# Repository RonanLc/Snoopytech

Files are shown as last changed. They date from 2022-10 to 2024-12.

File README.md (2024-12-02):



# Snoopytech - Autonomous Robot Dog 🐕

## 🌟 Presentation

Snoopytech is an ambitious project for an autonomous quadruped robot, designed to explore complex environments by combining agility and embedded intelligence. The robot uses 3-degree-of-freedom legs, brushless motors and integrates a computational architecture based on Arduino and NVIDIA. Behave or he might bite ! 

## ⚙️ Key features

1. **Mechanical structure** : 

   - 3-axis legs with brushless motors for smooth, dynamic movement.
   - Robust, lightweight design for stability in a variety of environments.

2. **Electronic components** :

    - **Arduino**: Sensor management and basic motion coordination.
    - **NVIDIA Jetson**: Advanced processing for computer vision, data analysis and real-time decision-making.
    - [**Brushless ACK-5312CP motors**](https://fr.aliexpress.com/item/33027613653.html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): Brushless motor for dog joint with reversible ESCs
    - [**RP LIDAR**](https://www.amazon.fr/Scanradius-LIDAR-Sensorscanner-Vermeidung-Hindernissen-Navigation/dp/B07VLFGT27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): 360° LIDAR for environmental analysis
    - [**C505e HD Webcam**](https://www.amazon.fr/Logitech-Webcam-Micro-Longue-port%C3%A9e/dp/B08NZ52YYN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): HD camera for environmental analysis
    - [**MPU6050**](https://fr.aliexpress.com/item/32340949017.html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): IMU sensor with accelerometers and gyroscopes

3. **Software and algorithms** :

   - Motor control via specific controllers (ESC).
   - Implementation of kinematic models to ensure precise movement.
   - Integration of sensors for autonomous navigation.

## 🎯 Project objectives

- Develop a robot capable of walking, running and adapting to rough terrain.
- Incorporate artificial intelligence for tasks such as obstacle detection, object recognition and interaction with the environment.
- Test and validate locomotion and stability algorithms for quadruped robots.

## 🛠️ Project structure

The repository is organized as follows:

1. `Mechanical/` :
   - CAD design files and mechanical drawings.
   - Documentation on leg manufacturing and motor selection.

2. `Electronics/` :
   - Circuits for powering motors and interfacing with control boards.
   - ESC configuration for brushless motors.

3. `Software` :
   - Arduino code for low-level control of motors and sensors.
   - Python and C++ scripts for data processing and behavior management.
   - Simulation models to test algorithms before hardware integration.

4. `AI/` :
   - Computer vision models for real-time analysis (via Jetson).
   - Learning algorithms to optimize motion.

## 🚀 Progress and next steps

- **Current**: Tests of locomotion algorithms and motor calibration.
- **Upcoming** :
  - Full integration of sensors for autonomous navigation.
  - Development of a communication system for remote or collaborative control.
  - Energy optimization for extended autonomy.

## 📚 Documentation

- **Tutorials and Explanations**: Sample scripts are available in the `doc/` folder.

## 📫 Contact

If you have any questions or suggestions, please feel free to open an issue or contact me via [my GitHub](https://github.com/RonanLc).

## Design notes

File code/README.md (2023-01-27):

# Bilan programmation du 27/01/2023

## Introduction

Ce répertoire rassemble tous les programmes et parcelles de code qui ont été crées/utilisés dans le cadre de ce projet.
Il s'agit, pour la plupart, de code C++ car nous sommes encore au stade d'expérimentation. 
Nous implementerons des fonctions de traitements d'images et de classifications d'images à bord de la Jetson Nano lorsque nous aurons achevé d'écrire les librairies destinées à rendre notre robot fonctionnel.

## Librairies et classes utilisées/importées

Voici une liste de librairie que nous utilisons afin de rendre certains capteurs/actionneurs opérationnels :

1. [I2Cdev](https://github.com/jrowberg/i2cdevlib) 

Cette librairie facilite le contrôle de module communiquant avec l'Arduino par le biais de bus I2C. Nous l'utilisons notamment dans la librairie ```MPU6050```.

2. [MPU6050](https://github.com/jrowberg/i2cdevlib/tree/master/Arduino/MPU6050)

Cette librairie est destinée à controler le capteur GY-521 (gyroscope). Elle permet d'utiliser le DMP (digital motion processor) qui est sollicité pour renvoyer des données stables et lisibles. 
Nous implementons cette librairie dans la classe ```Gyroscope```.

3. [ServoTimer2-master](https://github.com/nabontra/ServoTimer2)

Cette librairie permet de controler les servomoteurs et ESC de notre robot en évitant de créer des conflits liés au Timer1 de l'Arduino. Nous l'implementons dans la classe ```CameraMount```.

## Librairies et classes apportées

Cette section regroupe les classes et les programmes que nous avons écrits. 

1. [Gyroscope](https://github.com/RonanLc/Snoopytech/tree/main/code/lib/Gyroscope)

Cette classe facilite l'utilisation du gyroscope GY-521. Elle implémente les classes MPU6050 et I2Cdev. 

Utilisation: 
- permet d'initialiser un gyroscope sur le pin 2 d'une Arduino Uno
- calcule et renvoie l'accelération réelle et le roulis/tangage/lacet du capteur

2. [CameraMount](https://github.com/RonanLc/Snoopytech/tree/main/code/lib/CameraMount) 

Cette classe crée des objets contrôlant une nacelle de notre robot. Une nacelle est une structure sur laquelle se monte des capteurs qui ont besoin d'une orientation indépendante du corps du robot. La nacelle se compose de deux servomoteurs SG-90.

Utilisation:
- permet d'initialiser les deux servomoteurs sur les pins passés en paramètre
- change le roulis et/ou le tangage de la nacelle selon un angle passé en paramètre
- réinitialise la position de la nacelle 
- renvoie la postion de la nacelle

## Programmes d'essais

1. [rpm_brushless](https://github.com/RonanLc/Snoopytech/tree/main/code/test/rpm_brushless.ino)

Ce programme permet de récuperer la vitesse de rotation d'un moteur brushless grâce à un capteur à effet Hall. Nous l'utilisons dans l'étude de l'asservissement de position des moteurs. 

2. [main.cpp](https://github.com/RonanLc/Snoopytech/blob/main/code/src/main.cpp) 

Ce programme est celui qui sera exécuté sur l'Arduino. Il regroupe toutes les classes utilisées. 
Pour l'instant, il permet de changer l'orientation des deux nacelles du robot selon l'inclinaison du gyroscope. 

## Jetson Nano

Nous nous sommes initiés aux possibles librairies et structures proposées par Nvidia visant à faire de l'IA (classification d'image, détection d'objets, estimation de profondeur, ...) sur la Jetson Nano à travers le cours dédié de [Nvidia](https://developer.nvidia.com/embedded/learn/jetson-ai-certification-programs#course_outline). 
En lançant le conteneur docker dédié, nous avons rencontré de nombreux problèmes de librairies manquantes ou obsolètes et avons décidé de poursuivre sur d'autres logiciels. 
Nous nous sommes notamment intéréssés aux programmes chargés dans le conteneur [Hello AI World](https://github.com/dusty-nv/jetson-inference) qui ciblent davantage les besoins de notre projet (détection d'objets et estimation de profondeur). Cependant, lorsque nous tentons de lancer des programmes permettant de visualier ce que la caméra enregistre, des erreurs de librairies manquantes apparaissent. Nous pensons qu'il s'agit des librairies CUDA, CUDNN ou TensorFLow qui sont obsolètes.

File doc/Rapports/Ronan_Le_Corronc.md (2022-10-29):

# **New -** Week 43 - October 28, 2022 - 22h

## Shoulder preliminary conception 

The leg was finish so I start working about the motor part and mostly **the shoulder part**. I made a lot of sketching because this part is the **most complex** of the leg build.

The shoulder must fit a lot of part in it :
- The 2 motors of the legs
- The belt of the hip speed reduction
- The 2 potentiometers to check the knee and hip position
- A cable connector to power all the leg part
- The pullet for the shoulder rotation

The difficulty here is to fit every thing in the shoulder. But the shoulder must be very **compact, light and also have a good design.**

## Shoulder modeling

I decided to made the shoulder in **2 part**, one for the top and one for the bottom. These parts will be made with a **3D printer**.

So I start to modeling the part to fix the shoulder on the frame. I decided to made an other tube, around the carbon fiber tube with 2 bearings.

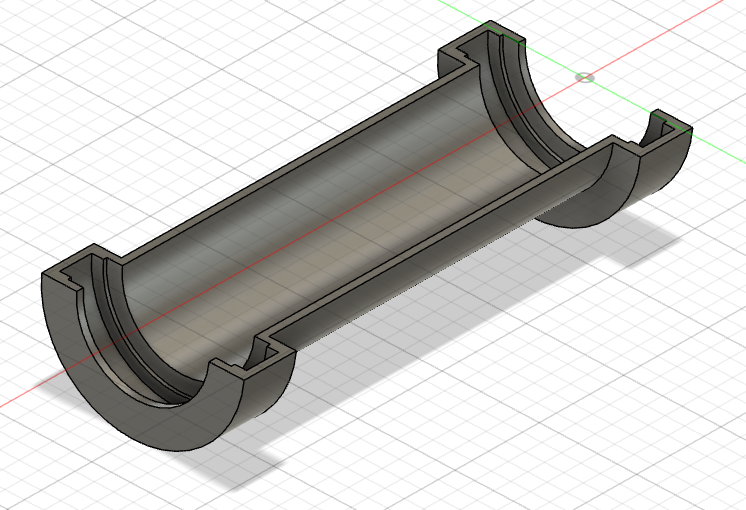
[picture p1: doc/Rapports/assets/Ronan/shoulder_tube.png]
Shoulder tube


After that I had to modeling someting to fix the 2 motors. I didn't want to fix the motors directly on 3D parts because it's not precise and solid enough.

So i decided to fix the motors on a **plexiglass piece**.

For that I modeled **a gutter** that can accommodate the plexiglass plate. So the 2 3D parts will close on the plexiglass piece.

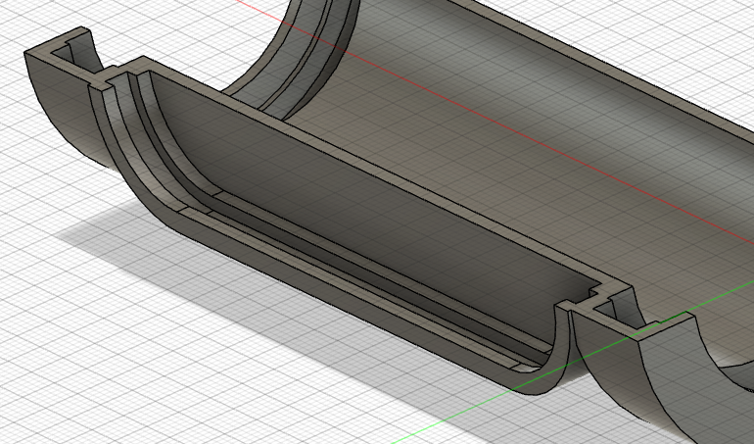
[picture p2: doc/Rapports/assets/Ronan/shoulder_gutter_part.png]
Shoulder gutter


The bottom part isn't finish yet but I start a assembly of the shoulder. I had the bottom and the top part, and the 2 bearing.

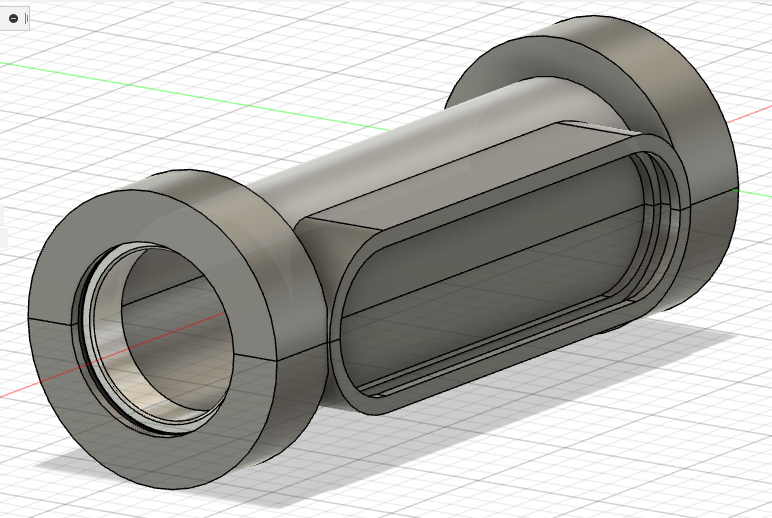
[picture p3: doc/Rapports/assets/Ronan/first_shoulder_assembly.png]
First shoulder assembly


## Next week

During the next I'll continue the shoulder part.

Now I need to focus on the motors fixation and the transmission part. When the transmission will be done, I'll fix the shoulder to the rest of the leg.
_________________________________________________________________

# Week 41 - October 14, 2022 - 7h

## **Component change**

During the design of the leg I realized a problem, **the rotary life** of [the potentiometers we had chosen](https://fr.aliexpress.com/item/32996236826.html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). They had a rotary life about **100 cycles** which is not enough. So we chose to start on [new potentiometers](https://fr.aliexpress.com/item/1005002766893077.html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,scm-url:1007.40050.281175.0,pvid:c4eb49e9-017c-42e1-bc5a-36d0b91caa96,tpp_buckets:668%232846%238116%232002&pdp_ext_f=%7B%22sku_id%22%3A%2212000022084500624%22%2C%22sceneId%22%3A%2230050%22%7D&pdp_npi=2%40dis%21EUR%210.42%210.37%21%21%21%21%21%402101f6b416658300092574280e1af7%2112000022084500624%21rec) with a rotary life about **10,000 cycles** which will be much more resistant.

So I updated the list of components available [here](https://github.com/RonanLc/Snoopytech/blob/main/doc/Rapports/Liste%20de%20composants.xlsx).

## **Important and modeling of default components**

After Maximilien created [a common project on Fusion 360](https://myetu3651.autodesk360.com/g/projects/20221014567544581/data/dXJuOmFkc2sud2lwcHJvZDpmcy5mb2xkZXI6Y28uNXprUVZwQ0VTM3VlQ1hmSjdNN09nQQ), I imported and modeled the components we will use like an Arduino Uno, a Nvidia JN30D and others. This will allow us to have accurate references for our modeling.

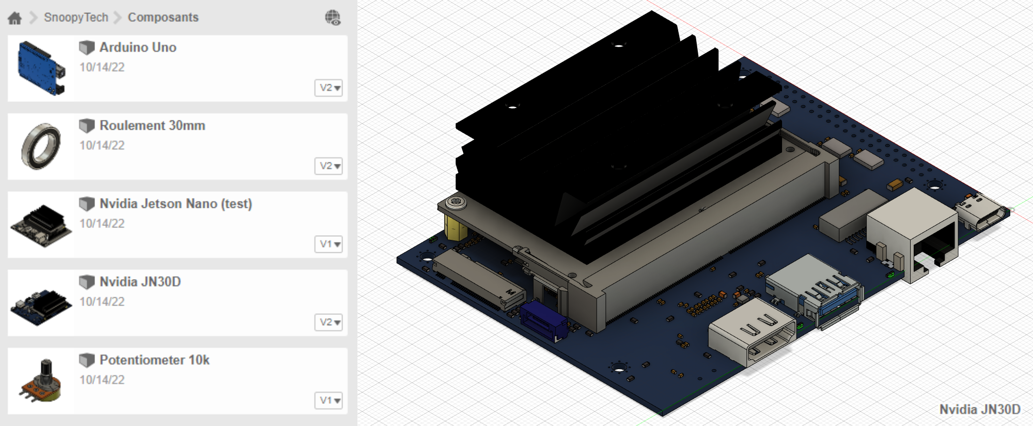
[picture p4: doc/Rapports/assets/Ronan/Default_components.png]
Default components


## **Research on leg transmission**

We were not yet decided on the transmission used for the legs of the robot. So I took the time to break down the possibilities to choose the best one.

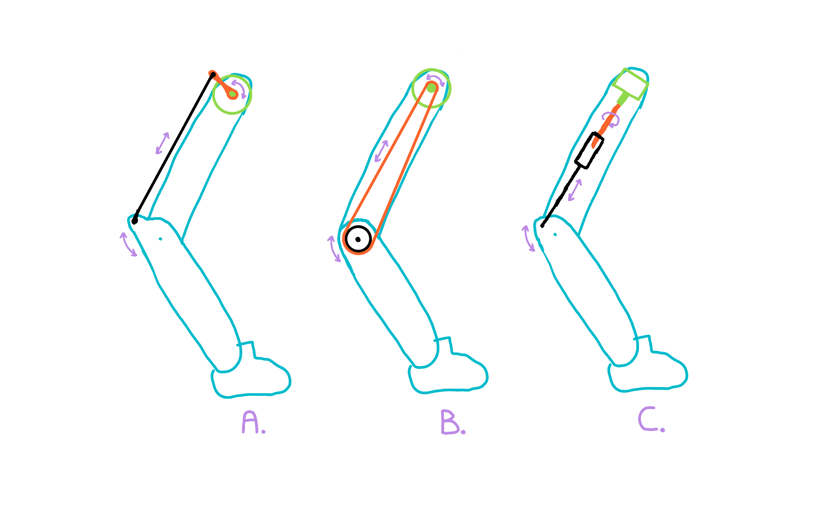
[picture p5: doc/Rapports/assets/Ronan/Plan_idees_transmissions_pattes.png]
Transmission ideas


I have therefore determined **3 possible transmissions** :

- **A.** With a connecting rod
- **B.** With a belt
- **C.** With a worm screw

Given the reliability and complexity of these transmissions, we have chosen to use the **B. transmission, with a belt**. It seems to be the most feasible and aesthetic. It will also allow us to use it directly as a gearbox.

## **Leg design**

So I started to think about the precise design of the leg and I chose to make it like the following sketch.

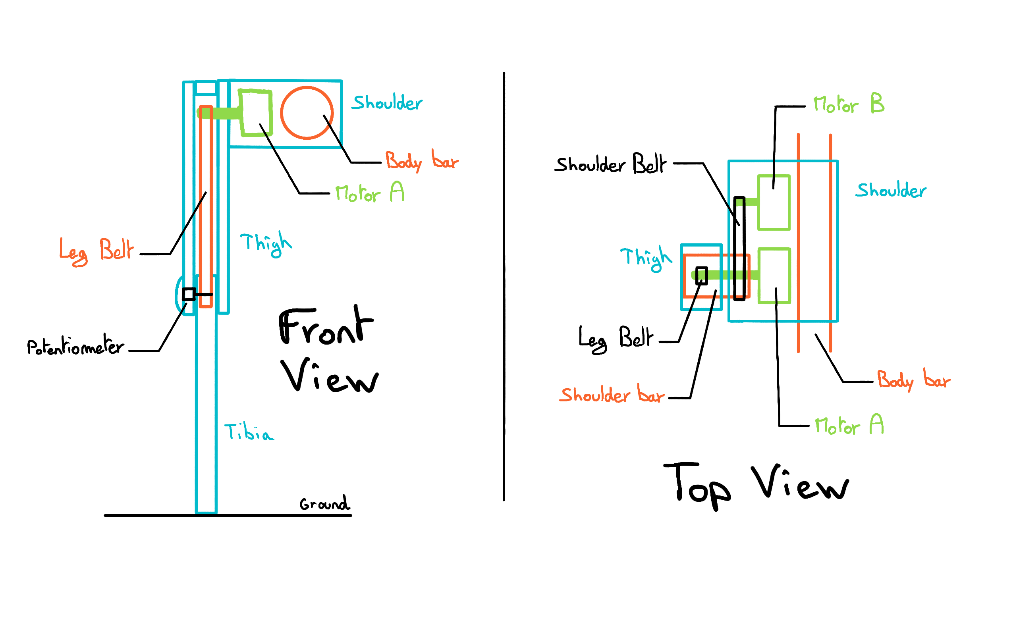
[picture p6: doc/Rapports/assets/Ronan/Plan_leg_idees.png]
Leg design Led design


So I started to model the leg but I haven't finished yet because of lack of time.

I modeled the shoulder tube used to rotate the leg. It is made of carbon so I entered its density (1.79g/cm3) in Fusion 360 to estimate the weight at the end.

I also modeled the ball bearing that will connect the leg to the shoulder.

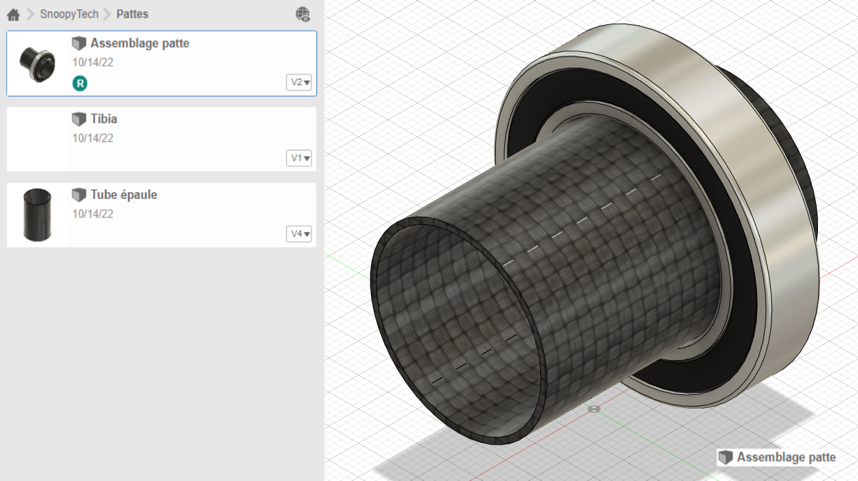
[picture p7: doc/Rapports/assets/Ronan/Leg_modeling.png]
Leg modeling


## **Next week**

I will concentrate next week on the modeling of the leg and its assembly with the different components.

My goal is to finish modeling the leg at the end of the next session. For that I still need to design the most solid and light solution of the leg.

Once that is done, I can start modeling the shoulder and then the junction with the rest of the body.

# Week 42 - October 18, 2022 - 17h

I focused this week on the robot leg. I looked at its design, its performance and how can I build something strong and light.

## **Leg schematic**

I realized that most of the existing robots were still designed in a similar way.

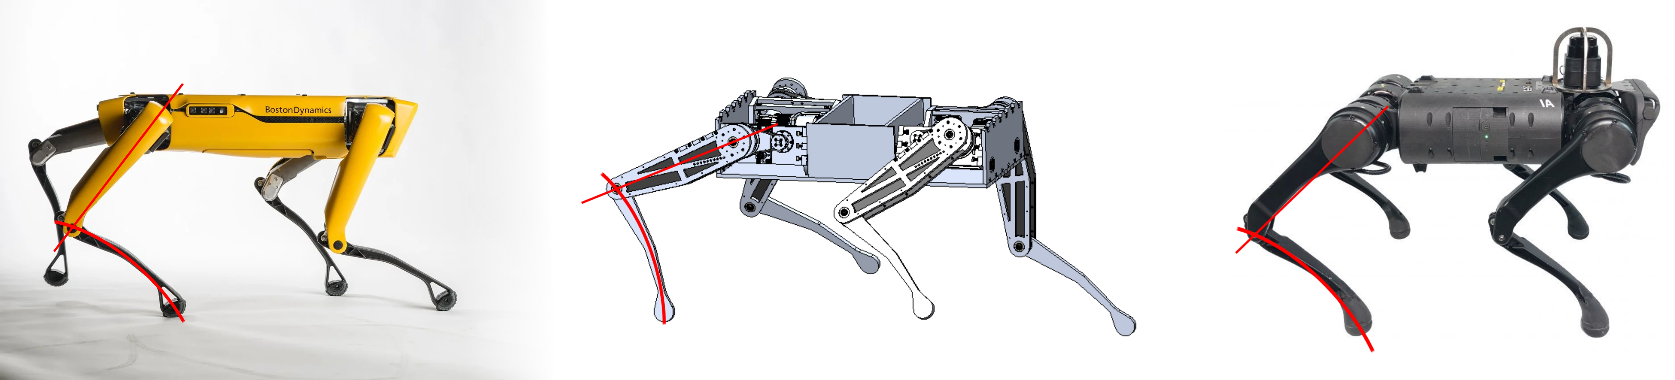
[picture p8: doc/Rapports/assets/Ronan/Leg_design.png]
Leg design


They all have a straight thigh and then a curved tibia so I decided to base the leg on that.

The thigh and the shin being generally of the same size, I decided to make the thigh and the shin of 15cm. This will allow us to make the robot go up to 30cm high in case we have to overcome big obstacles. This will also be more than enough to climb the steps.

## **Modeling of the leg**

As indicated in our report, I designed the thigh and the tibia so that they can be cut out of plexiglass. This will allow us to quickly change these parts if there is a problem because they are parts that will undergo strong constraints.

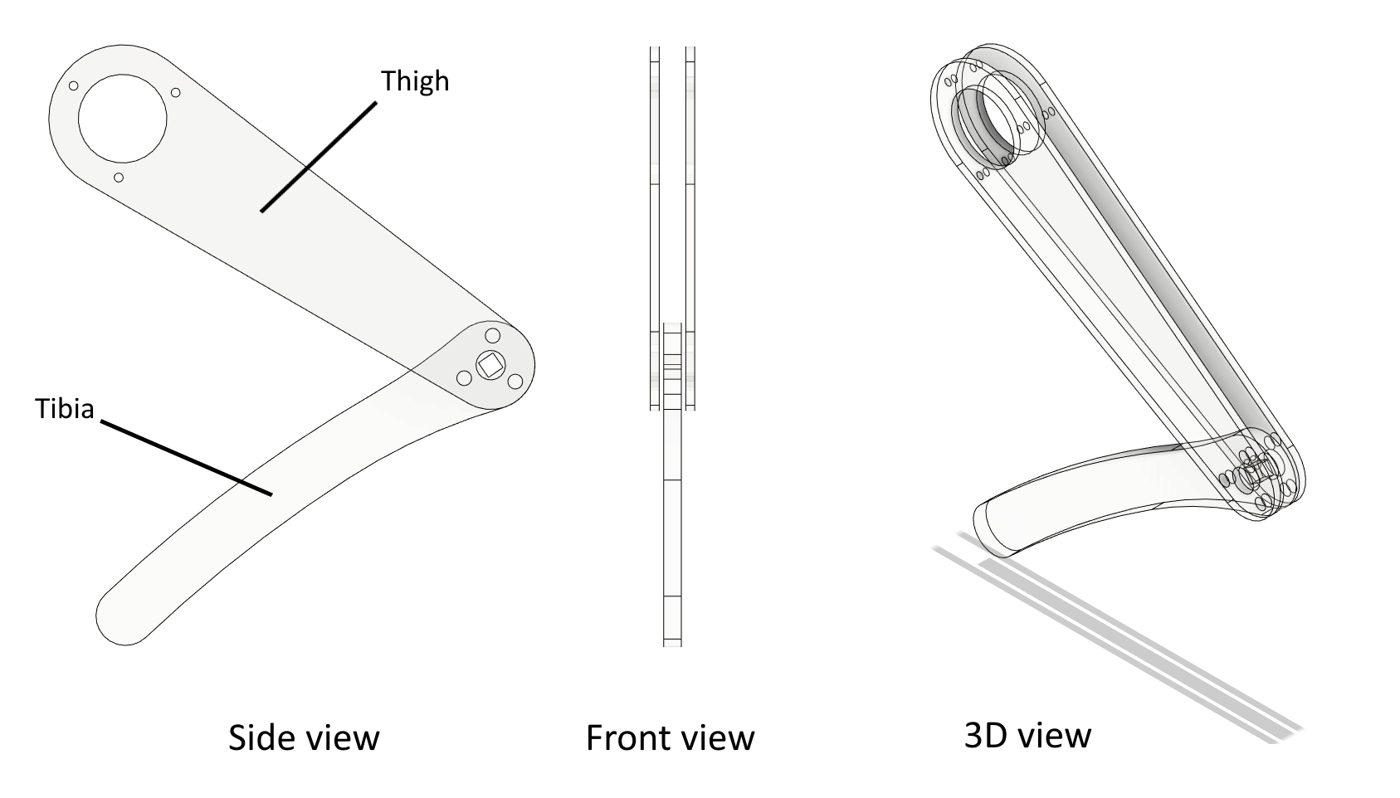
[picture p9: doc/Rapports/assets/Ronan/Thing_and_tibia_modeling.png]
thigh and tibia modeling


I then modeled the knee joint, then the hip joint. I decided to use mainly 3D printing to design the parts that hold the bearings.

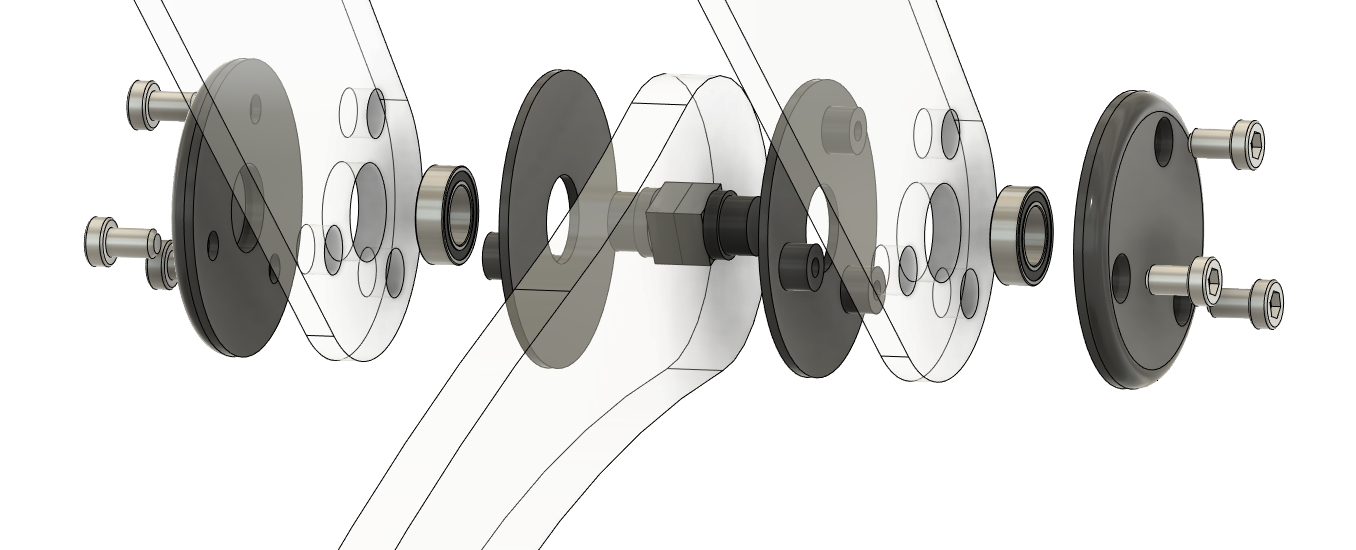
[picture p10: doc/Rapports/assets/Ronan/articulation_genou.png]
knee joint


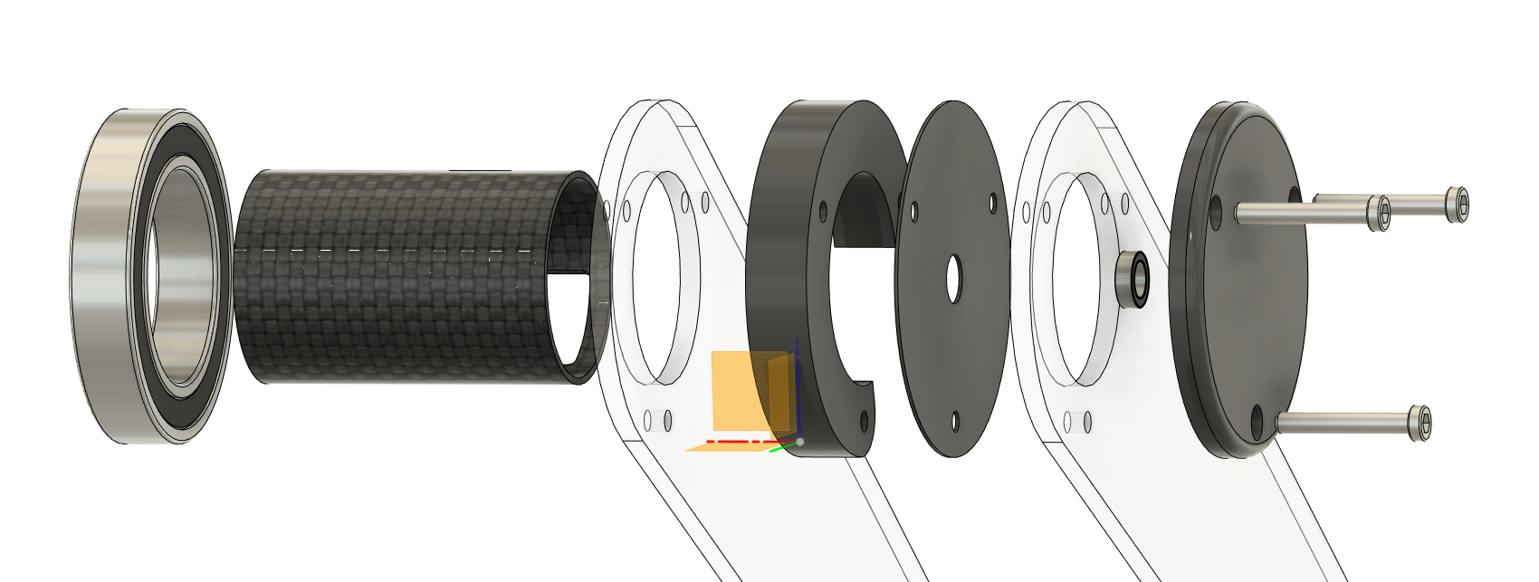
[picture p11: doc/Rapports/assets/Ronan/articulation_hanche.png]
hip joint


The joints are almost finished. I have set up the materials of each part to have an idea of the weight of our future legs.

leg mass Leg mass

So now we have the look and design that our leg will have, this gives us an idea of the visual that our robot will have and also the weight and capabilities.

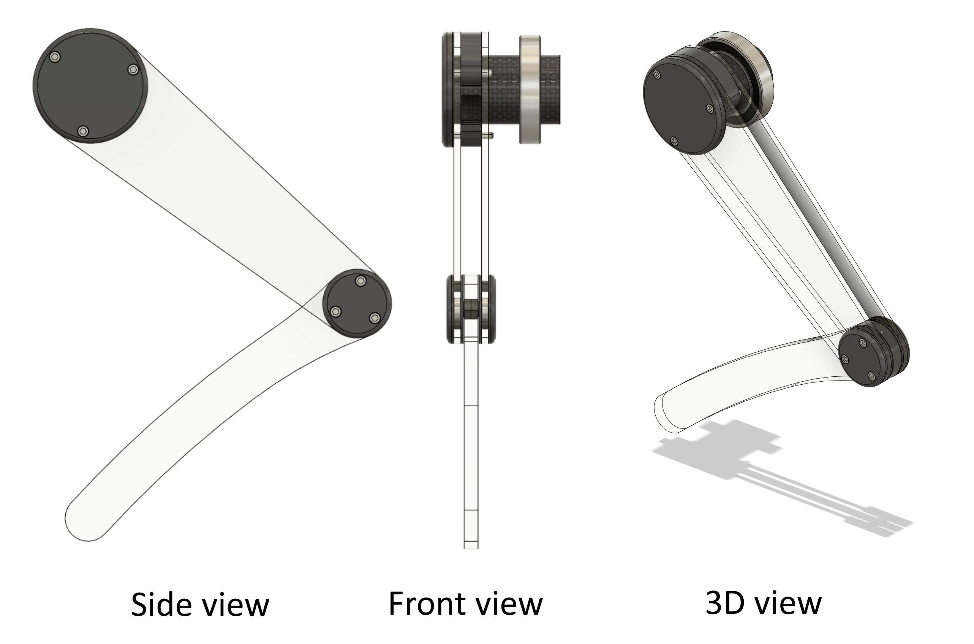
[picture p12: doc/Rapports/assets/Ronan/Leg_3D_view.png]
total leg view


## **Next week**

The joints are now almost finished so I'm going to focus on modeling the transmissions and the motorization next week.

The next step will also be to design the shoulder which will contain the motors and the position sensors. Then to focus on the connection with the body. This will allow us to start the complete assembly of the robot and correct the different errors before starting the production.

# Week 43 - October 28, 2022 - 22h

## Shoulder preliminary conception 

The leg was finish so I start working about the motor part and mostly **the shoulder part**. I made a lot of sketching because this part is the **most complex** of the leg build.

The shoulder must fit a lot of part in it :
- The 2 motors of the legs
- The belt of the hip speed reduction
- The 2 potentiometers to check the knee and hip position
- A cable connector to power all the leg part
- The pullet for the shoulder rotation

The difficulty here is to fit every thing in the shoulder. But the shoulder must be very **compact, light and also have a good design.**

## Shoulder modeling

I decided to made the shoulder in **2 part**, one for the top and one for the bottom. These parts will be made with a **3D printer**.

So I start to modeling the part to fix the shoulder on the frame. I decided to made an other tube, around the carbon fiber tube with 2 bearings.

Shoulder tube

After that I had to modeling someting to fix the 2 motors. I didn't want to fix the motors directly on 3D parts because it's not precise and solid enough.

So i decided to fix the motors on a **plexiglass piece**.

For that I modeled **a gutter** that can accommodate the plexiglass plate. So the 2 3D parts will close on the plexiglass piece.

Shoulder gutter

The bottom part isn't finish yet but I start a assembly of the shoulder. I had the bottom and the top part, and the 2 bearing.

First shoulder assembly

## Next week

During the next I'll continue the shoulder part.

Now I need to focus on the motors fixation and the transmission part. When the transmission will be done, I'll fix the shoulder to the rest of the leg.

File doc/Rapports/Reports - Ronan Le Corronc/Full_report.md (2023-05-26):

# Week 41 - October 14, 2022 - 7h

## **Component change**

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

So I updated the list of components available [here](https://github.com/RonanLc/Snoopytech/blob/main/doc/Rapports/Liste%20de%20composants.xlsx).

## **Important and modeling of default components**

After Maximilien created [a common project on Fusion 360](https://myetu3651.autodesk360.com/g/projects/20221014567544581/data/dXJuOmFkc2sud2lwcHJvZDpmcy5mb2xkZXI6Y28uNXprUVZwQ0VTM3VlQ1hmSjdNN09nQQ), I imported and modeled the components we will use like an Arduino Uno, a Nvidia JN30D and others. This will allow us to have accurate references for our modeling.

Default components

## **Research on leg transmission**

We were not yet decided on the transmission used for the legs of the robot. So I took the time to break down the possibilities to choose the best one.

Transmission ideas

I have therefore determined **3 possible transmissions** :

- **A.** With a connecting rod
- **B.** With a belt
- **C.** With a worm screw

Given the reliability and complexity of these transmissions, we have chosen to use the **B. transmission, with a belt**. It seems to be the most feasible and aesthetic. It will also allow us to use it directly as a gearbox.

## **Leg design**

So I started to think about the precise design of the leg and I chose to make it like the following sketch.

Leg design Led design

So I started to model the leg but I haven't finished yet because of lack of time.

I modeled the shoulder tube used to rotate the leg. It is made of carbon so I entered its density (1.79g/cm3) in Fusion 360 to estimate the weight at the end.

I also modeled the ball bearing that will connect the leg to the shoulder.

Leg modeling

## **Next week**

I will concentrate next week on the modeling of the leg and its assembly with the different components.

My goal is to finish modeling the leg at the end of the next session. For that I still need to design the most solid and light solution of the leg.

Once that is done, I can start modeling the shoulder and then the junction with the rest of the body.

# Week 42 - October 18, 2022 - 17h

I focused this week on the robot leg. I looked at its design, its performance and how can I build something strong and light.

## **Leg schematic**

I realized that most of the existing robots were still designed in a similar way.

Leg design

They all have a straight thigh and then a curved tibia so I decided to base the leg on that.

The thigh and the shin being generally of the same size, I decided to make the thigh and the shin of 15cm. This will allow us to make the robot go up to 30cm high in case we have to overcome big obstacles. This will also be more than enough to climb the steps.

## **Modeling of the leg**

As indicated in our report, I designed the thigh and the tibia so that they can be cut out of plexiglass. This will allow us to quickly change these parts if there is a problem because they are parts that will undergo strong constraints.

thigh and tibia modeling

I then modeled the knee joint, then the hip joint. I decided to use mainly 3D printing to design the parts that hold the bearings.

knee joint

hip joint

The joints are almost finished. I have set up the materials of each part to have an idea of the weight of our future legs.

leg mass Leg mass

So now we have the look and design that our leg will have, this gives us an idea of the visual that our robot will have and also the weight and capabilities.

total leg view

## **Next week**

The joints are now almost finished so I'm going to focus on modeling the transmissions and the motorization next week.

The next step will also be to design the shoulder which will contain the motors and the position sensors. Then to focus on the connection with the body. This will allow us to start the complete assembly of the robot and correct the different errors before starting the production.

# Week 43 - October 28, 2022 - 22h

## Shoulder preliminary conception 

The leg was finish so I start working about the motor part and mostly **the shoulder part**. I made a lot of sketching because this part is the **most complex** of the leg build.

The shoulder must fit a lot of part in it :
- The 2 motors of the legs
- The belt of the hip speed reduction
- The 2 potentiometers to check the knee and hip position
- A cable connector to power all the leg part
- The pullet for the shoulder rotation

The difficulty here is to fit every thing in the shoulder. But the shoulder must be very **compact, light and also have a good design.**

## Shoulder modeling

I decided to made the shoulder in **2 part**, one for the top and one for the bottom. These parts will be made with a **3D printer**.

So I start to modeling the part to fix the shoulder on the frame. I decided to made an other tube, around the carbon fiber tube with 2 bearings.

Shoulder tube

After that I had to modeling someting to fix the 2 motors. I didn't want to fix the motors directly on 3D parts because it's not precise and solid enough.

So i decided to fix the motors on a **plexiglass piece**.

For that I modeled **a gutter** that can accommodate the plexiglass plate. So the 2 3D parts will close on the plexiglass piece.

Shoulder gutter

The bottom part isn't finish yet but I start a assembly of the shoulder. I had the bottom and the top part, and the 2 bearing.

First shoulder assembly

## Next week

During the next I'll continue the shoulder part.

Now I need to focus on the motors fixation and the transmission part. When the transmission will be done, I'll fix the shoulder to the rest of the leg.

# Week 46 - November 15, 2022 - 26h

## Receiving and adding 3D parts

We have received some parts that we ordered. This will allow us to start the construction of the robot but first to finalize its 3D design.

We received the 30mm bearings, the belts, the pulleys of belts, a part of the ESC. So we have all these components:

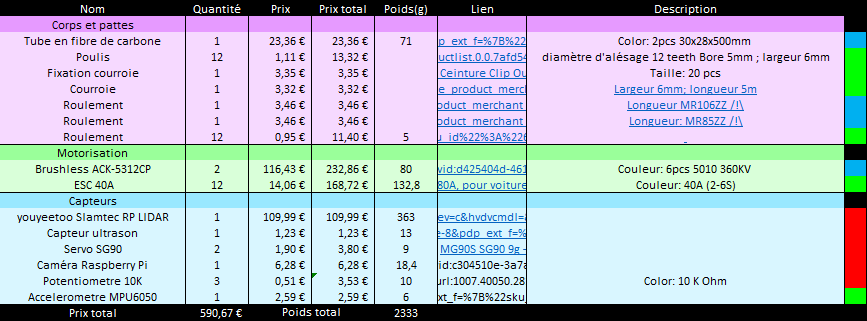
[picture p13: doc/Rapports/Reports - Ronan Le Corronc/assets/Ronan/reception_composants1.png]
Components reception


*Green: components received / Blue: components waiting / Red: components without information*

So I was able to model some parts like the belt pulley.

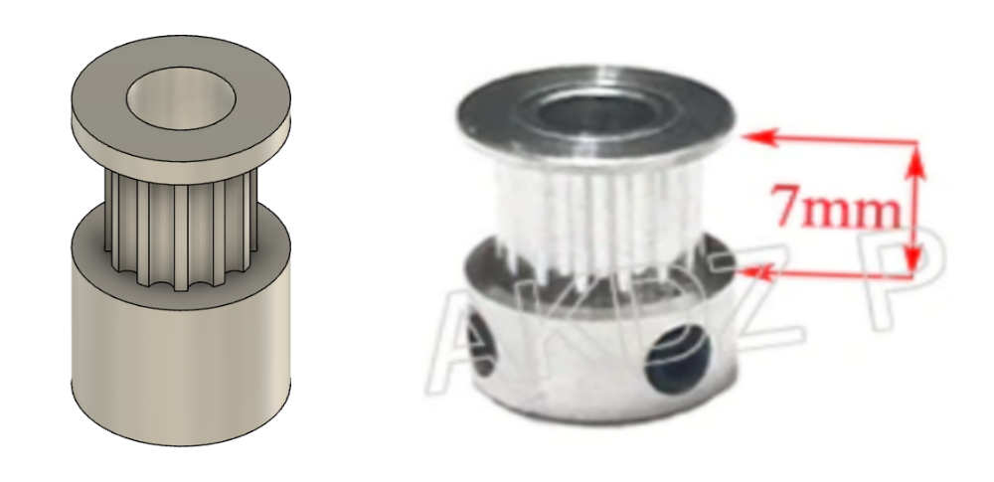
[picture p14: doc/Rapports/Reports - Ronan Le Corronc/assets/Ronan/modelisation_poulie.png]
3D pulley


## Shoulder modeling

I continued the modeling of the shoulder of the robot. I modeled the plexiglass plate that will hold the motors. It will slide between the upper and lower part of the shoulder.

So I could add the motors to the assembly and continue to model the shoulder shells to enclose them.

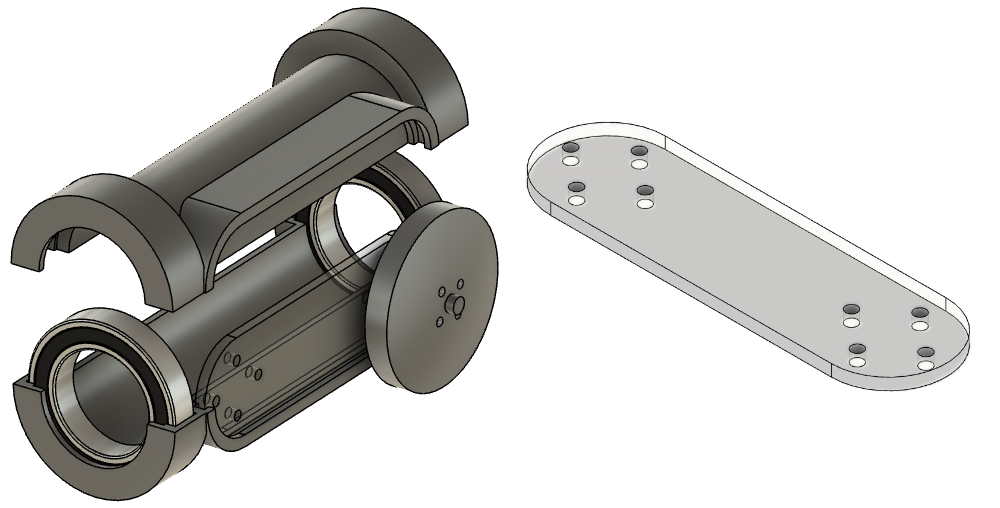
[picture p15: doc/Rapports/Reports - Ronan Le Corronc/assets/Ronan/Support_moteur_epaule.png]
Shoulder modeling


## Shoulder and leg assembly

With the motors added, I was able to continue modeling the shoulder and then assemble the leg to the rest of the assembly.

I added links to connect the angular displacement of the legs and the motors. But the reduction is still to be determined.

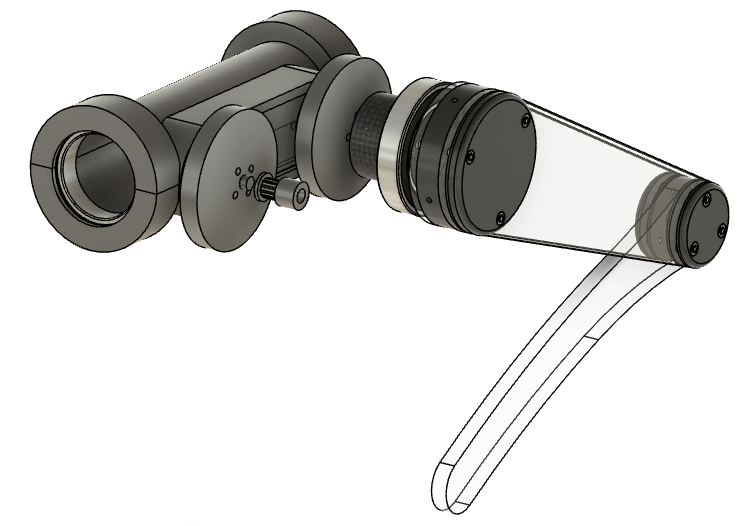
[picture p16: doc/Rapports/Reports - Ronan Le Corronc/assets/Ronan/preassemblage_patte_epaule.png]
Shoulder and leg assembly


## Next week

I will focus on the attachment of the leg to the shoulder. The system must be reliable and strong. 

I will also add to the shoulder the mechanism with the potentiometers to measure the position of the legs.

Depending on the progress, we will be able to start building the robot at the end of the session.

# Week 47 - November 25, 2022 - 30h

We received the last components at the beginning of the session so I focused my session on working on the motors.

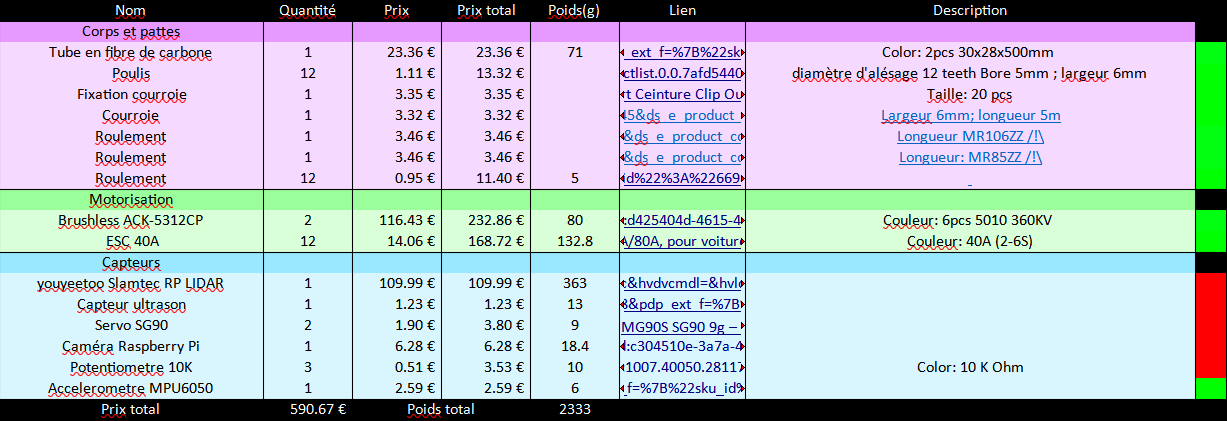
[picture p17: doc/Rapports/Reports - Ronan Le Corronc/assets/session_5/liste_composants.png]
Components list


*Green: components received / Blue: components waiting / Red: components without information*

We now have all the main components to build the robot.

<br>

## Préparations des moteurs

Before starting to use the motors, some preparation has to be done. Here we received connectors with the motors so I decided to solder them to the motors and ESCs to easily connect them.

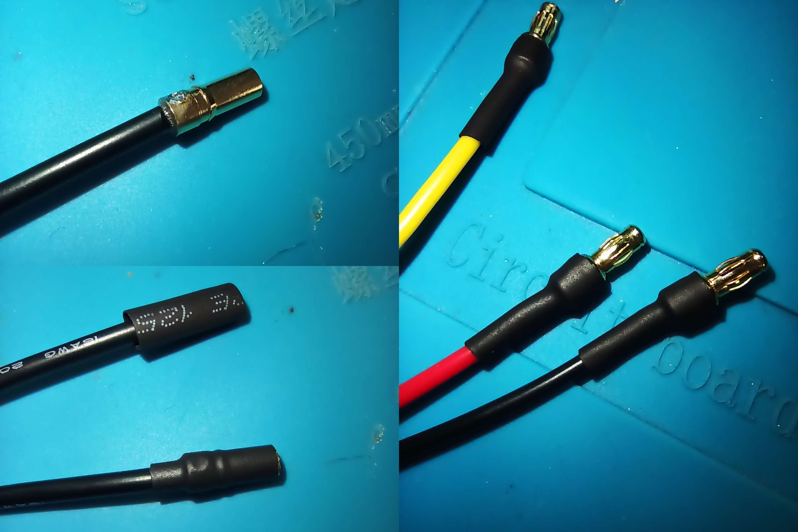
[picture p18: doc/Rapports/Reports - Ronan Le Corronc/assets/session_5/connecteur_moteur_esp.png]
Soldered connectors


Motors and ESCs can therefore be easily connected and disconnected.

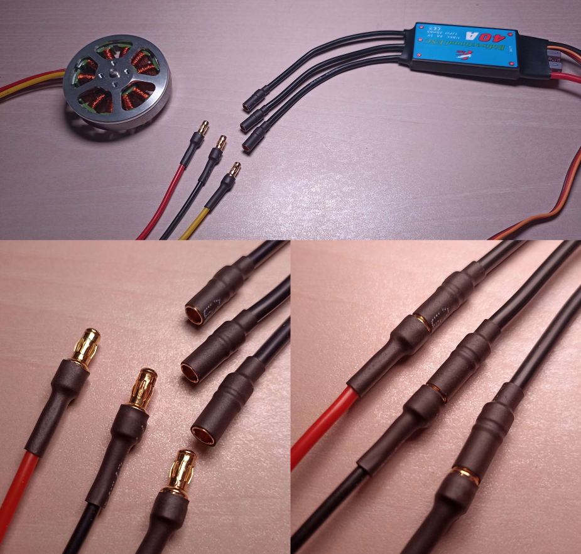
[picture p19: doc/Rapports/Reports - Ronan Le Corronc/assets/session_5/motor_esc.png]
motor and esc


<br>

## Electric assembly

Thanks to these connectors I could assemble the electrical system for the motors. It is composed of a motor, an esc, and an arduino board and a potentiometer to drive the motor.

the electrical circuit is composed as follows:

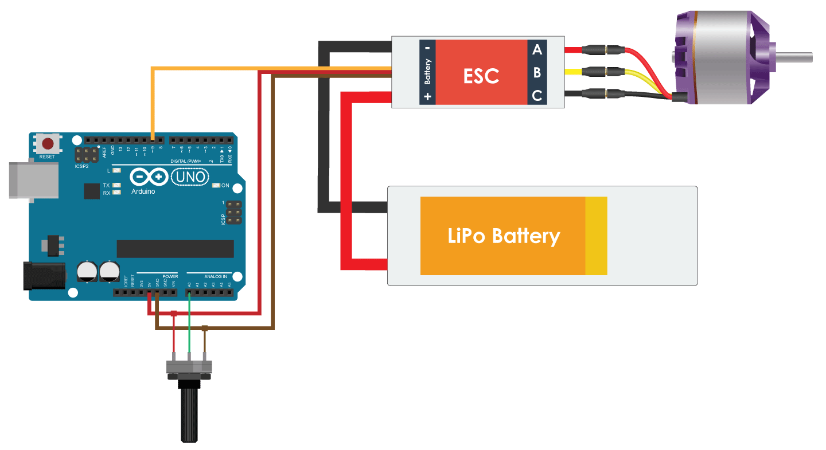
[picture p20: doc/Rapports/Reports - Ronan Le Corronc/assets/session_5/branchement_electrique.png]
electric assembly


The LiPo battery here has been replaced by a DC voltage generator set to 15V to simulate the connection to a LiPo 4S.

The potentiometer will be used to select the speed of rotation of the motor and its orientation.

<br>

## Motor programming

Many methods exist to control the motor, or to control the esc. Here I use an arduino board and after many tests I discovered that some ESCs can be controlled the same way as a servo motor.

That is to say that it is controlled by PWM. This allows to indicate to the ESC the desired motor speed.

So I tested a very simple program using the arduino library for servo motors.

```ino
#include <servo.h>
```
The program works in a very simple way. It recovers the value that the potentiometer returns (corresponding to its position) and converts it in a proportional way to send it in pwm to the ESC.

```ino
#include <Servo.h>

Servo esc;
int pot;

const int pinPot = A0;
const int pinEsc = 5;

void setup() {
  esc.attach(pinEsc, 1000, 3000);
  Serial.begin(9600);
}

void loop() {
  pot = map(analogRead(pinPot), 0, 1023, 0, 180);
  Serial.println(pot);
  esc.write(pot);
  delay(10);
}
```

And here are the very first turns of the motor of our future robot!

first turns of the robot's motor (https://youtu.be/H11FsNPKSh8)

During this test I noticed two things. First, the motor doesn't seem to be going at its maximum speed so the pulse durations of the pwm would have to be changed. Second, the PWM is also used to change the direction of rotation of the motor.

The next command allows to choose the orientation of the servo motor normally. It supports an input from 0 to 180.

```ino
esc.write(90);
```

From ``90`` to ``0`` the motor turns in one direction.

*0 is supposed to be the maximum speed of the motor.*

<br>

And from ``90`` to ``180`` the motor turns in the other direction.

*180 being supposed to be the maximum speed of the motor.*

<br>

## Next week

We will start building the robot. The conception is almost finished which will allow to do the first tests of the legs in the next sessions.

The library for the servo motor works well but it is not optimized for brushless motors, at least not for this ESC.

So I'll be interested in the programming of the motor and find codes to exploit 100% the possibilities of the motor. I will also try to drive several motors at the same time.

<br>

# Week 49 - December 6, 2022 - 44h

Before starting to assemble the motor with the legs we had to know if our motors are well sized for our robot.

<br>

## Motor power

To know if our motors will be powerful enough we want to know their speed and torque.

To do this we can ask these different variables :

```
N : Motor rotation speed (in rpm).

U : Electrical supply voltage of the motor

I : Current flowing through the motor

Ri : Real internal resistance of the motor

Io : No-load current

Kv : Speed constant of the motor (here we use a 320kv motor)

Pe : Electrical power of the motor

Pj : Joule effect losses

Po : Internal friction losses

Ps : Motor output power

C : Mechanical torque at motor output
```

<br>

First of all let's calculate the torque. To do this we will calculate it thanks to the power of the motor. Several characteristics apply to electric motors and brushless motors are no exception. Here are their respective formulas :

<br>

Motor speed : 
$$ \text{N = Kv} \times \text{(U - I} \times \text{Ri)} $$ 

Electrical power consumption :
$$ \text{Pe = U} \times \text{I} $$

Joule effect loss :
$$ \text{Pj = I2} \times \text{Ri} $$

Internal friction losses :
$$ \text{Po = (U - I} \times \text{Ri)} \times \text{Io} $$

<br>

We can therefore calculate the power output of the motor with the losses.

$$ \text{Ps = Pe - Pj - Po} $$

$$ \Leftrightarrow \text{Ps = U} \times \text{I - I2} \times \text{Ri - (U - I} \times \text{Ri)} \times \text{Io} $$

$$ \Leftrightarrow \text{Ps = (U - I} \times \text{Ri)} \times \text{(I - Io)} $$

We also know that the output power is :
$$ \text{Ps = N} \times \text{C} $$

<br>

We can therefore write the equality linking the torque to the electrical characteristics of the motor.

$$ \Leftrightarrow \text{N} \times \text{C = (U - I} \times \text{Ri)} \times \text{(I - Io)} $$

$$ \Leftrightarrow \text{N} \times \text{C = } \frac{N}{Kv} \times \text{(I - Io)} $$

$$ \Leftrightarrow \text{C = } \frac{(I - Io)}{Kv} $$

<br>

From the constructed information we deduced that we could estimate ``(I - Io) = 20A``.

Which gives us:

$$ \text{C = } \frac{20A}{320kv} \text{ = 0.0625 N.m}$$

<br>

Let's focus now on the speed.

We know that on a brushless motor the speed is defined by :

$$ \text{N = U} \times \text{Kv} $$

Here we intend to use 4s batteries.

$$ \text{N = (3.7V} \times \text{4)} \times \text{320Kv = 4736 rpm} $$

<br>

So we have a motor running at ``N = 4736 rpm`` for a torque of ``0.0625 N.m``.

<br>

## Required power calculation

We now need to determine the power we will need.

In the bibliographic report we estimated that the robot would be about 4kg in total. That is 1kg per leg.

When designing the legs I chose to size them in two parts of 150mm.

$$ \text{1kg} \times \text{9.81m/} s^2 \times \text{0.3m = 1.4715 N.m} $$

This means that the robot will have to support a torque of ``1.4715 N.m`` to be able to stand up when the legs are positioned as follows.

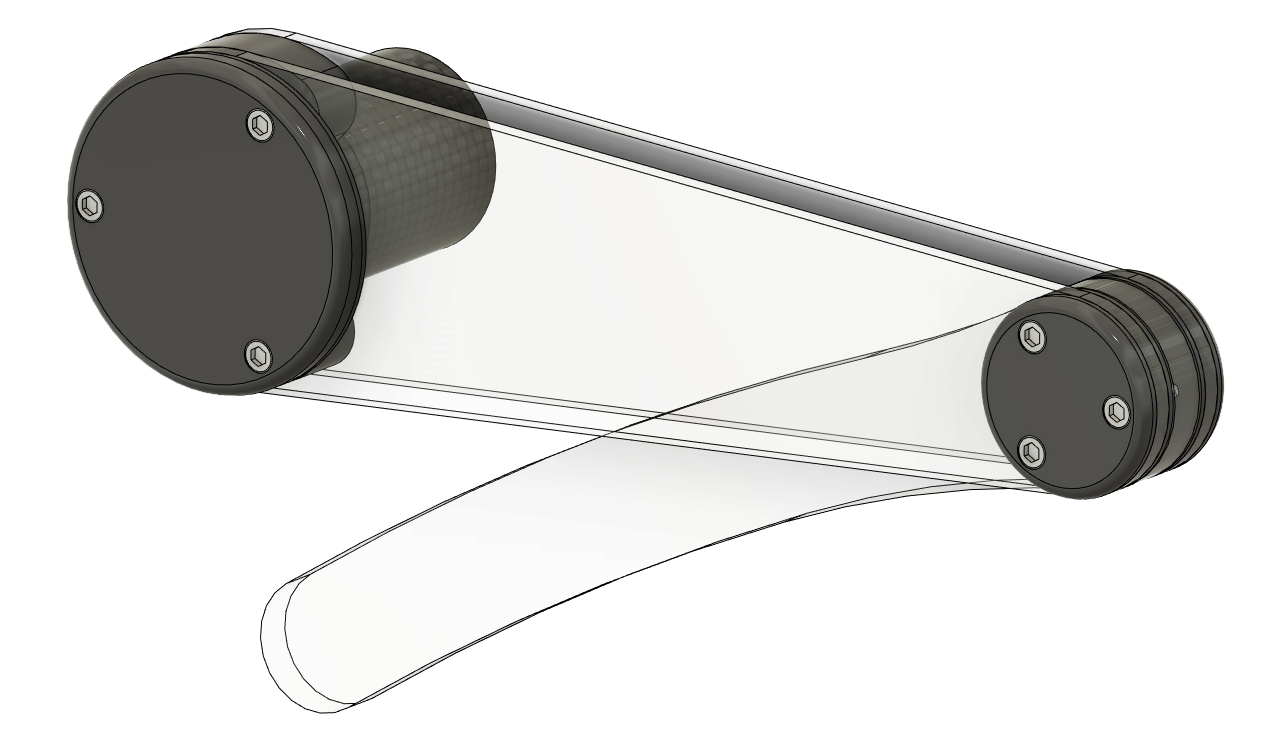
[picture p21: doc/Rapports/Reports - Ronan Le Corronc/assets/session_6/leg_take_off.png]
leg position


<br>

## Reducing calculation

Now we have to determine the gearbox we will need.

To do this I relied on the speed of rotation.

<br>

I estimated that our leg should move at a maximum speed of 1.5 rps. This will give us good mobility and responsiveness.

$$ \text{1.5 rps = 90 rpm} $$

$$ \frac{4736 rpm}{90 rpm} \simeq \text{52.6} $$

So I estimate that I need a gearbox of about 1/50 to fully utilize the capacity of the motors.

<br>

Knowing the torque of the motor, we can therefore estimate the torque applied to the shaft of the legs.

$$ \text{0.0625 N.m} \times \text{50 = 3.125 N.m} $$

Knowing that we needed ``1.4715 N.m``, the robot will have the power to carry more than twice its weight and thus have a significant payload.

<br>

## Reducing agent used

Several possibilities are available for the reducers.

### Buy our reducers

The first one was to buy steel ones. They will be flawless and resistant, just what we need.

Unfortunately, the ones on the market are not adapted to our motors and therefore it would have complicated our task greatly. Moreover, these reducers are often very expensive and we did not want to increase the cost of our robot unnecessarily.
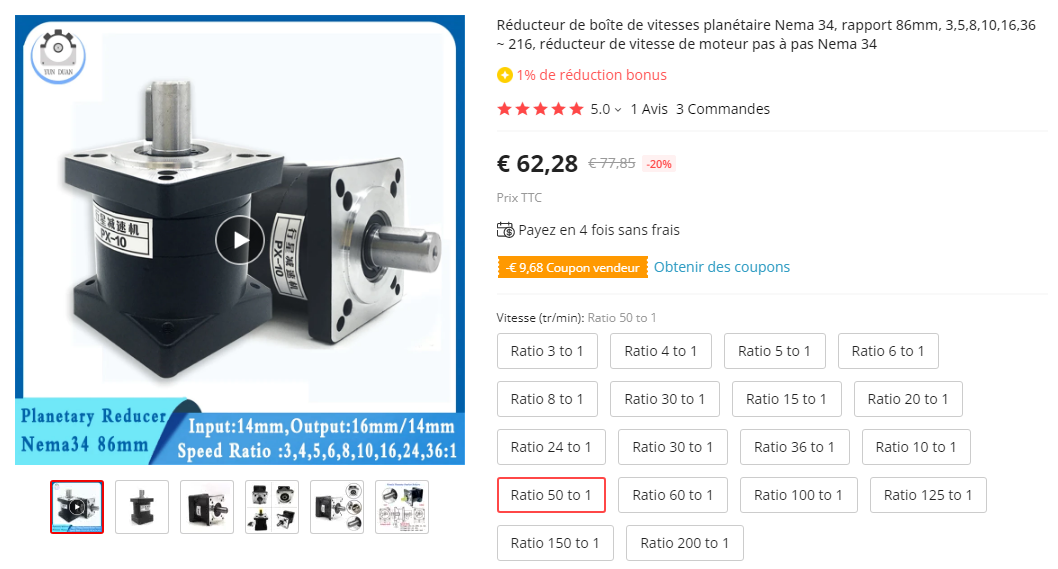
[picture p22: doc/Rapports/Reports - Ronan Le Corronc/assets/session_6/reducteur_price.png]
Reductor price


We have therefore chosen to design our own gearboxes.

<br>

### Making with belts

The second solution considered was to design a system with several pulleys and belts in series.

After many tests and calculations I obtained conclusive results for different designs.

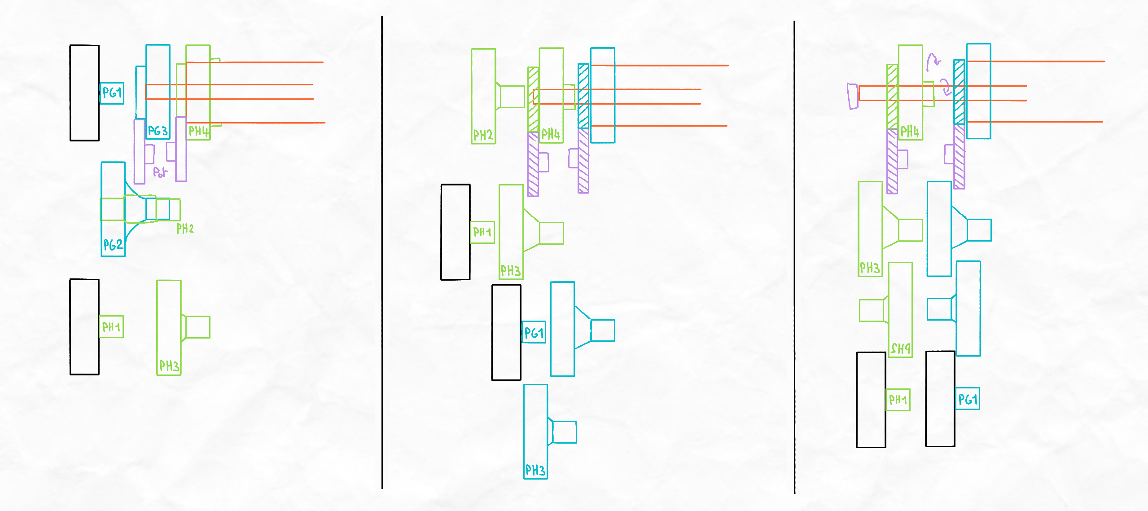
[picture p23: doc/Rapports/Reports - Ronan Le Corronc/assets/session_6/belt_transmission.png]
belt transmission


*Blue : knee transmission | Green : hip transmission | Purple : Potentiometers | Black : Motors*

But I encountered a big problem with this system. We had to use closed belts because some pulleys will make more than one full turn. And unfortunately the smallest belts on the market are 120mm. This is way too big for our system. So I had to abandon the transmission with the belts.

<br>

### Making with gears

So I turned to gears which will have allowed me to solve this problem.

The problem with the gears is that the teeth and the axles are highly solicited.

And our manufacturing means are limited so we would have to make them in 3D printing and I was afraid that it would not be strong enough in time and that our system would not have any play.

So I abandoned the idea.

<br>

### Manufacture epicyclic gears

At least not totally. After some research on the internet I discovered the existence of epicyclic gearboxes (or planetary gearboxes).

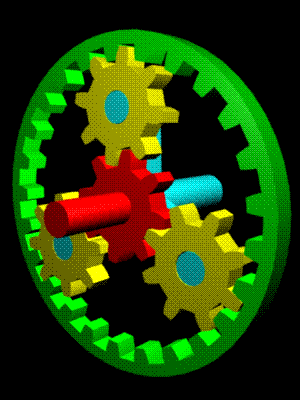
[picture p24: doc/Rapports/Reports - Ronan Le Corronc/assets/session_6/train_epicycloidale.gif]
train épicycloïdale


This system works with gears but the system is perfectly balanced. It is known to be more resistant, to have less play but especially, to be able to pass more torque than with simple gears.

So I chose to use this system.

<br>

## Next session

I will focus on the sizing of the gearbox and its design.

<br>

# Week 49 - December 9, 2022 - 59h

## Gearbox sizing

I had several constraints to determine how I was going to make the gearbox.

The first one was the maximum size of the large pinion. I didn't want to go more than 50mm over the diameter (stator size of the motor) to not have too big parts in the shoulder.

I chose to use a 1.2 pitch for the gears. This means that here I would use an external pinion of 40 teeth:

$$ \text{40} \times \text{1.2 = 48mm} $$

And my second constraint was the size of the pinion connected to the motor. To be able to aim it on the rotor without worries, I needed a pinion of more than 18mm. So I chose to use a 20 teeth pinion.

$$ \text{20} \times \text{1.2 = 24mm} $$

An epicyclic gear is composed of 4 different parts. 

- The central pinion (Red) named ``P`` for the continuation
- The crown gear (Green) named ``C`` for the continuation
- The satellites (Yellow) named ``S`` for the continuation
- The satellite holder (Cyan)

In view of my constraints I decided to divide the gearbox in 3 parts. I will put in series 2 epicycloidal trains (R1 & R2) then a gearbox with a belt (R3).

<br>

After reading up on epicyclic gears, I discovered that there are several rules to follow when determining which pinion sizes to use.

- Reduction ratio for the fixed gear :

$$ \frac{Zp}{Zp + Zc} $$

- Number of teeth of the parts :

$$ \text{Zc = Zp + 2} \times \text{Zs} $$

- Number of satellites (Nbr):

$$ \frac{Zp}{Zs} \text{+ 1  = Nbr} $$

<br>

We can therefore determine the following equation :

$$ \text{R1 + R2 + R3 = Rtotal} $$

$$ \Leftrightarrow \frac{20}{20 + 40} \times \frac{x}{x + 40} \times \frac{12}{y} = \frac{1}{50} $$

<br>

Let's determine ``x`` :

$$ \text{Zc = Zp + 2} \times \text{Zs} $$

$$ \Leftrightarrow \frac{Zc - Zp}{2} \text{ = Zs} $$

$$ \Leftrightarrow \frac{Zp \times 2}{Zc - Zp} \text{+ 1 = Nbr} $$

$$ \Leftrightarrow \frac{Zc \times (Nbr -1)}{1 + Nbr} \text{ = Zp}$$

For the best stability I chose to put 3 satellites.

$$ \frac{40 \times (3 - 1)}{1 + 3} \text{ = 20}$$

This gearbox will therefore be sized like the first one.

$$ \frac{Zc - Zp}{2} \text{ = Zs} $$

$$ \frac{40 - 20}{2} \text{ = 10} $$

So we have all the sizes of the gears for the planetary gearing:

- Zc = 40 teeth
- Zp = 20 teeth
- Zs = 10 teeth

It remains now to determine the size of the pulley for the last gear (y):

$$ \frac{20}{20 + 40} \times \frac{20}{20 + 40} \times \frac{12}{y} = \frac{1}{50} $$

$$ \frac{20}{20 + 40} \times \frac{20}{20 + 40} \times 50 = \frac{y}{12} $$

$$ \frac{20}{20 + 40} \times \frac{20}{20 + 40} \times 50 \times 12 = y $$

$$ y \simeq 66 $$

The last calculation being an approximation because we cannot have a decimal number of teeth. The final reduction ratio will be :

$$ \Leftrightarrow \frac{20}{20 + 40} \times \frac{20}{20 + 40} \times \frac{12}{66} = \frac{1}{49.5} $$

But this will in no way prevent the gearbox from working properly.

<br>

## Gearbox modeling

The epicyclic gearbox is therefore composed of 13 parts shown below and 8 ball bearings.

reduct parts

So I put it all together to get the following setup:

reduct assembly

These parts will be printed with an SLA printer. I felt that the uncertainty of FDM printing would not be strong enough and would have too large an area of insertitude.

So I was able to assemble the leg to these reducers. The design is not finished yet and some details are still to be modified but we can already have an idea of the general shape of the final assembly of the leg.

leg assembly

<br>

## Gearbox printing

My big concern about this gearbox was the feasibility. The gears must be strong enough to support the torque and the speed. The bearings must have no backlash to minimize friction. And the gears must not have any play either or the system will fail.

Since we are going to use 3D printing I was very doubtful that it would really work.

So I decided to print a few parts so I could try and learn about SLA printing.

3D printed part

The parts went on correctly. I had no problems with it and the accuracy of the parts surprised me. There doesn't seem to be any uncertainty like with FDM printing. I am finally very optimistic about the manufacturing of this system.

<br>

## Next week

So now I'm going to focus on building the system by running as much printing as possible and continuing to correct and modify the errors I encounter on the 3D design.

<br>

# Week 50 - December 14, 2022 - 64h

## Gearbox printing

After having completely modeled the different elements of the transmission and the gearboxes, I started to print them.

For this I had to learn how to use SLA printing. This printing is more complex than FDM printing.

It works in different steps:

### 1 - Slicing the parts

This step is necessary to prepare the printer plate and to choose the printing parameters of our parts and supports.

Slicing screenshot

### 2 - Printing

After the previous step we send the file to the printer. We set the printer to the right resin and then we start printing.

SLA printing is faster than FDM printing. Here for a complete plate I had 1h30.

Printing

### 3 - Cleaning

For the parts printed in resin it is necessary to clean them, to remove the resin still liquid on the parts.

To do this we bathe them in a vat of alcohol. Here I used Draft V2 resin so I immersed the parts for 10min.

### 4 - Curing

The last step is to harden the parts. When they come out of the printer, the resin is still a bit soft and the parts remain malleable. Once they are well cleaned, we expose them to strong UV rays for 5 minutes in a closed chamber.

After this step the parts are finished.

<br>

## Problems encountered

During this first printing I encountered several problems.

### Printing uncertainty

Every 3D print has an uncertainty and I couldn't find on the internet the one for the SLA print.

During the first print I did last week I had a 4.9mm axis for a 5mm bearing and it turns out that there was, I think, a lot of play. So I felt that 1mm was way too much.

So I tried to remove all the uncertainties. Make 5mm pins for 5mm bearings.

Of course it didn't work. I still managed to make the assembly but the system is almost impossible to turn and no bearings can go to the places intended for.

Blocked system](assets/session_8/blocked_system.png)

The parts of this system are completely blocked and cannot be removed.

After doing some tests I concluded that the uncertainty of the SLA print is about ``0.05mm``.

### Print media

Another problem was the print media.

Resin printing holds a lot to the platen, especially when we print flat surfaces. To remedy this, we use supports that will raise the part.

Not using a support is very efficient but the parts are very complicated to retract. To do this, you have to force them, which means you either damage the parts or injure yourself.

injury

The problem is that the result with and without supports is completely different. With supports the print is not flat and creates a surplus of material on the surface.

with and without supports

*Here on the left **with** / on the right **without***

The piece on the left has been sanded. We tried to correct this error by sanding the pieces with Maximilien.

Maximilien le ponceur (https://www.youtube.com/shorts/yaIJI3Ak4zo)

But the results were not very convincing. The parts remain inaccurate and we lose a lot of time during the manufacturing process to sand each part. We will have to continue printing without supports.

## Next session

I will continue to print the reducers but this time by correcting the uncertainties.

<br>

# Week 50 - December 16, 2022 - 72h

## Gearbox printing

So I changed the uncertainty of the parts and I reprinted them. This time I did not have any problem during the printing and the system is correctly mounted.

Assemblage transmission

I still have some corrections to make because the box doesn't close due to offsets (like on the picture on the left).

The gears are white because of the friction between the parts, the parts wear while turning and the resin tends to whiten very quickly. But the parts are still efficient before turning.

The friction is still a problem, despite the reduced tolerance. The motor still manages to turn the parts easily but it would be better to apply **grease** to the final assembly.

After discussing with a teacher we also concluded that we could use sheets of **teflon** under the gears to limit the friction with the fixed parts.

Limiting this friction would in first, **limit the wear of the parts** and in second, **limit the heating of the system**.

We were still able to install the bearings in the parts.

Bearings and parts

<br>

## Tests
We have verified that the reduction ratio is indeed 1/3 for one stage and we could test to make the motor turn with the reducer.

bearing and parts (https://youtu.be/gItiiFNIVas)

The reducer makes a lot of noise due to the gear play and the noise of the plastic but this should be manageable with some grease.

<br>

## Next session

So I will continue to work on the reducers and the goal of the next session will be to have a finished reducer of the right size to be able to print several of them.

<br>

# Week 3 - January 16, 2023 - 106h

## Modification of the gearbox

The gearboxes have been completely modified.

I changed a lot of insertitude to have a functional system and to do some tests. There is now some play between the gears but it is a play that we can correct as we go along.

The whole gearbox has also been printed in PLA instead of resin. The goal was to print a gearbox as quickly as possible and therefore not to bother with the resin.

The fixations of the gearbox have also changed. Instead of having two small screws holding the whole thing I installed 4 M4 screws on both sides to hold it firmly.

Gearboxs

<br>

## Prototype of a leg

For the presentation of Monday January 16th we wanted to present a functional paw. Due to lack of time I focused on one joint, the knee. So I made a prototype of the paw by modifying some parts to make only the knee move.

The reducer was fixed to the hip as if below.

Hips

<br>

## Transmission

The gearbox is not the only part of the transmission and speed reduction. There is another reducer thanks to a belt. Here for the knee, this reduction is done between the two plates of the leg corresponding to the thigh.

A steel pulley of 12 teeth is connected to the axis of the reducer. Then, another pulley of 66 teeth is connected to the part of the leg corresponding to the tibia.

I installed a belt between the two to connect them. This belt is not closed, its end is aimed at the tibia, it goes around the pulley of 12 teeth and then returns to screw in the tibia.

The tibia has therefore been modified to make room for the belt. The axis of the tibia is no longer aligned with the axis of rotation of the knee.

tibia

tibia

<br>

## Construction

All the pieces were cut and assembled.

You can find some videos here below.

[Testing the PLA planetary gearbox](https://youtu.be/Rsbbrvysg-4)

[Installation of the knee belt](https://youtu.be/3-rBXzxxJk4)

[How the gearbox works](https://youtu.be/zriuFQDhgsk)

The knee could be correctly assembled and we could make the tests of the functioning. It moved corrector in both directions.

The test can be seen [here](https://youtu.be/JdPR6T-Bgfs).

I purposely left the sound on to hear the reducer. It is very noisy, this is due to the play between the gears and also to the fact that I have not yet put any grease or oil to lubricate the gearbox. This will be added later.

## Next

It remains now to build the rest of the leg, the hip joint. Then to correct as much as possible the play in the reducer.

<br>

# Week 5 - January 31, 2023 - 114h

## Modification of the gearboxes

A first problem on the reducers was encountered during the first tests : the paste did not always follow the movement of the motor. It was getting out of sync with the gearbox.

And there is a simple reason, the steel shaft controlling the belt was slipping in the gearbox.

Reducer V1

As shown on the picture, the axle was only sliding in the part that was supposed to drive the movement of the lug and so it was sliding when the system was asking for the least torque.

I changed this so that the two parts stay well linked during the movements.

I simply cut a flat on the axis and added a nut with a screw inside the part.

Reducer V2

After retesting, this solution solved the problems of slippage and play. The system is now solid and resists high torque.

<br>

## Resizing of parts

The previously modified part is at the heart of the reducer. Since it has been enlarged to accommodate the life in its thickness. I had to modify all the other parts of the system so that it doesn't create an offset.

I also modified the shoulder modeled by Maximilien so that it could match the new dimensions of the reducers.

Leg assembly

<br>

## Problem with the belts

We encountered a problem during the new tests. When we apply a high torque to the system the belt jumps and does not transmit the motion.

We discovered that the reason was that the belt was not tight enough. The belt is connected with screws on both ends. It was difficult to tighten it when we aimed the screws.

So I added a system on the thigh of the robot allowing to tension the belt with a screw.

Belt tensioner

Belt tensioner schematic

The lower part of the tensioner will come against the belt and therefore will tension it. We can adjust the tension with the screw (in yellow on the schematic) then a screw passing through the hole of the blue part will lock the position of the tensioner.

The system is a first version and may need to be improved. It is possible that the friction of the tensioner with the belt due to the tension is too high. In this case it will be necessary to install a bearing.

<br>

## Next

We still have to add the potentiometers on the joints. Then we will be able to print the whole robot.

<br>

# Week 6 - February 7, 2023 - 122h

## Installation of the potentiometers

We now had to install the potentiometers within the system to be able to have a feedback on the position of the joints.

The main difficulties were to design simple, reliable systems with as little change as possible in the design of the robot.

Maximilien Kulbicki took care of the hip joint and I took care of the knee and shoulder joints.

### **1 - The knee**

For the knee, I dismantled the potentiometers to keep only two pieces. This allowed to save a lot of space because the potentiometers were very imposing.

The two parts are a fixed part, having the tracks (the brown part) and a mobile part making the contact between these tracks (the white part).

pot knee

So I used the steel axis of the joint. This one will be fixed to the tibia and will turn if we move this joint. I fixed the mobile part to it.

And with the help of a 3D printed part I could connect the fixed part to the thigh. These two parts will vary according to the movement and we can know the position.

To connect the axle to the mobile part, I wanted to drill the axle in its length and come to tarod it. Because of the lack of material, the operation seemed complicated. Pascal Masson helped me to find a solution and succeeded in cutting the axis so that it could be assembled directly.

Steel axis

### **2 - The soulder**

For the shoulder I used the same two pieces of the potentiometer. I positioned the mobile part on the shoulder shell and the fixed part on the frame.

pot shoulder

The mobile part will be through a carbon tube that will be fixed to the bearing of the shoulder shell.

The fixed part will be attached to a 3D printed part that will be fixed inside the carbon tube.

<br>

## Assemblage de l'épaule

After finishing the potentiometers and correcting the last errors. We were able to start prototyping a leg.

I printed a version of the shell in a beautiful color and assembled the different components inside.

montage 1

montage 2

montage 3

The parts fit together perfectly and the system has very little play for the moment.

It remains however to print a gearbox and re-cut the steel axes of the system.

<br>

## Next

The goal is to have a prototype of leg before the next vacations. I think it's possible.

We only have to print a gearbox, cut the steel axles, then make the final assembly with the belts.

<br>

# Week 7 - February 14, 2023 - 128h

## Printing the reducer

We were missing a reducer to finish the leg, so I printed it in PLA and assembled it.

Some parts had a printing problem so I had to go back twice.

We had enough bearings to make two so the gearbox was almost complete, it just lacked the steel shaft for the output rotation.

Reducer

<br>

## the assembly of the knee

The knee is composed of two main parts:

- one that we will consider fixed here, it is composed of the two plates of the thighs, the external protections and the potentiometer.

leg part 1

- the second one which is mobile, it is composed of the tibia, the steel axis and the second part of the potentiometer.

leg part 1

I had to re-cut the plexiglass plate of the second part. I also had to find a solution to fix the steel axis to the plexiglass plate.

So I chose to use the same technique used in [the reducers](https://github.com/RonanLc/Snoopytech/blob/main/doc/Rapports/Reports%20-%20Ronan%20Le%20Corronc/Session_11.md). I drilled the plate in its length and came to screw in a screw pressing on the rod.

axis fixation

I also soldered 3 wires on the potentiometer to allow to get the position of the potentiometer.

We tested the values it returns but we have a problem with it, it only works on a certain range then returns 0 afterwards. I suspect that the potentiometer track was scratched during disassembly or assembly. We will have to correct this problem.

The leg is fully assembled and fits perfectly with the shoulder.

Maximilien took care of re-cutting the axles for the reducers and so we will be able to connect all the systems together with the belts.

System picture

<br>

## Next

The goal is now to make the first tests of movement with the leg and torque tests.

After that we will be able to focus on the position control of the leg and the production of the 3 other legs!

<br>

# Week 9 - February 28, 2023 - 132h

During this session I decided to start working on the math to direct the robot.

When the legs are finished, the goal is to make the robot move. Unfortunately, pre-recording movements like walking or turning is not enough. Based on this alone the robot will not be able to adapt to uneven terrain or changing loads. It must be able to find its own balance and adapt to any situation.

So I try to determine different benchmarks on the robot and the equations allowing to go from one benchmark to another.

## Definition of the benchmarks

I have defined 5 different marks on the robot.

- Rc : The reference centered in the middle of the robot, the one of the building
- Rfl : The marker at the end of the left front foot
- Rfr : The mark at the end of the right front foot
- Rbl : The marker at the end of the left rear foot
- Rbr : The mark at the end of the right rear foot

I drew plans of the robot to locate them in space. The markers are thus placed as follows:

robot markers

This will allow us to determine rotations and movements in space, according to the benchmarks.

<br>

## Kinematic study

I have redrawn the robot in three dimensions to be able to determine the mathematical equations that will be useful to move the robot.

I defined different names of axes and rotation as shown in the diagram.

3D view

To simplify the calculations I started by studying the tibia and the thigh. So the axis of rotation of the knee and the hip. This allows us to start the calculations in 2D like the following diagram:

2D view

The goal was to move from the R1 to the RL positions. Unfortunately I did not manage to have conclusive results for the moment.

<br>

## Next

So I will focus on the mathematics to help find the equations to change the benchmark.

<br>

# Week 10 - March 7, 2023 - 136h

## Communication in Nvidia Jeston nano and Arduino UNO

The goal here is to be able to communicate between the two boards. 

The Arduino board will be used as a low level board, it will apply the commands of the Nvidia and will control the different sensors and motors.
The Nvidia card will be used to perform all the calculations and data analysis to determine the movements of the robot.

The two cards must be able to communicate with each other without stopping.

both card

<br>

## Wiring

The wiring is quite simple, you just have to connect the RX of the arduino to the TX of the Nvidia. Then connect the RX of the Nvidia to the TX of the arduino.

But when I looked a little bit more closely, I noticed a problem. The serial communication of the Nvidia works in 3.3V unlike the arduino which works in 5V. In the direction Nvidia -> Arduino, this is not a problem, the arduino will be able to read the bits received in 3.3V. But in the opposite direction you have to lower the voltage, the 5V can damage the Nvidia card.

I thought at first to use only a voltage divider bridge. But according to my research, it works very well at low frequency, but by increasing the communication speed, we risk to lose a lot of bits.

The solution was to add a level shifter, a small component designed for this use allowing to communicate with two different voltages.

So the wiring is like this:

Wiring

<br>

## Programming

The code is composed of two scripts, one in C that is run on the arduino and one in Python run on the Nvidia.

The ``Python`` code is as follows:

```Arduino
void setup(){
  Serial.begin(115200);
  while(!Serial){;}
}

const char stopPoint = '|';

void loop(){

  if (Serial.available()>0) {

    String commandFromJetson = Serial.readStringUntil(stopPoint);

    String ackMsg = "Message :" + commandFromJetson;

    Serial.print(ackMsg);
  }
  
  delay(500);
}
```

Here the code is only designed to receive a message from the serial communication and display it on the serial monitor.

The ``Python`` code is as follows:

```Python
import serial
import time

#arduino = serial.Serial('/dev/ttyAcM0', 115200, timeout=5)

arduino = serial.Serial(
port = '/dev/ttyACM0',
baudrate = 115200,
byterate = serial.EIGHTBITS,
parity = serial.PARITY_NONE,
stopbits = serial.STOPBITS_ONE,
timeout = 5,
xonxoff = False,
rtscts = False,
dsrdtr = False,
writeTimeout = 2)

while True:
    try:
        arduino.write("Command from Jetson|".encode())
        data = arduino.readline().decode()
        if data:
            print(data)
        time.sleep(1)
    except Exception as e:
        print(e)
        arduino.close()
```

This code is designed to first set the communication port and then, if everything works well, send the data to the arduino via the serial link. I use the ``serial`` library for that.

<br>

## Next

For the moment the communication works only by connecting the Arduino board in USB to the Nvidia. The Nvidia board has only one USB port which is already used for the camera, so we have to free it by using the RX/TX pins. Unfortunately the communication does not work via these ports. The problem seems to come from the port declaration in the Python script, the port used is not the right one.

So I will have to find the right port and redo some tests to have a reliable and functional communication.

<br>

# Week 11 - March 13, 2023 - 140h

During this session I concentrated on printing parts. The robot's paste being soon finished, we have to print all the parts to be able to build the three others quickly.

So I printed some parts that were already working.

## Gearbox

reducer

<br>

## ESC bed

ESC bed stack

ESC bed empty

ESC bed full

The ESC beds are not very strong though. They bend when I hang all the ESCs on them, so I would have to modify them to fit more rigidly.

<br>

## Shoulder case

Shoulder close

Shoulder open

The shoulders had to be reprinted many times because a lot of movements take place inside, we encountered many conflicts.

<br>

## Next

I continue to print parts as soon as possible and modify them when necessary to finish the robot as soon as possible.

<br>

# Week 12 - March 21, 2023 - 143h

During this session I focused on the laser cut parts. I modified the tibia by removing the 3D printed part at the strap. So we have only one piece in plexiglass which is much more resistant.

tibia 3D

tibia

I was also able to help Maximilien to make the body of the robot, so we cut the many plexiglass plates. Printed the parts allowing the assembly. And made a first assembly of the body.

Body view

<br>

# Week 13 - March 28, 2023 - 149h

During this session I focused on the kinematic study of the robot. As explained in [Report No. 14](https://github.com/RonanLc/Snoopytech/blob/main/doc/Rapports/Reports%20-%20Ronan%20Le%20Corronc/Session_14.md) we have to find the mathematical formulas allowing to pass from an orthonormal reference X Y Z to the angles of the leg.

I decided to start over because my previous calculations were underdeveloped and wrong.

## Schematics and name

For these calculations I used the following notations and diagrams:

schematics

**Mx**, **My**, **Mz** correspond to the desired X, Y, Z displacement.

<br>

## Direct equations

So I was able to determine the following equations:

$$ AB^2 = A^2 + B^2 - 2 \times A \times B \times cos(\textcolor{green}{\Theta}) $$

$$ \textcolor{red}{Mx} \text{ = L } \times \text{cos(} \textcolor{green}{\Psi} \text{) + AB } \times \text{cos(} \textcolor{green}{\Phi} \text{ - arcsin(} \frac{A \times sin(\textcolor{green}{\Theta})}{AB} \text{))} \times \text{sin(} \textcolor{green}{\Psi} \text{)} $$

$$ \textcolor{red}{My} \text{ = L } \times \text{sin(} \textcolor{green}{- \Psi} \text{) + AB } \times \text{cos(} \textcolor{green}{\Phi} \text{ - arcsin(} \frac{A \times sin(\textcolor{green}{\Theta})}{AB} \text{))} \times \text{cos(} \textcolor{green}{\Psi} \text{)} $$

$$ \textcolor{red}{Mz} \text{ = AB } \times \text{sin(} \textcolor{green}{\Phi} \text{ - arcsin(} \frac{A \times sin(\textcolor{green}{\Theta})}{AB} \text{))} $$

These equations correspond to the direct equations, they allow to obtain the X, Y, Z positions by knowing the angles of the robot legs.

## Next

I will focus on the inverse equations, the ones that allow to find the angles of the leg by knowing the X, Y, Z positions.

<br>

# Week 14 - April 4, 2023 - 155h

I determined last week the direct equations, so now I have to find the inverse equations.

To do this I based myself on the same diagrams.

schematics

## Inverse equations

So I was able to determine the following equations:

$$\textcolor{red}{ABo} = AB \times cos(\textcolor{green}{\Phi} - arcsin( \frac{A \times sin(\textcolor{green}{\Theta})}{AB} ))$$

$$ \textcolor{green}{\Theta} = arccos( \frac{A^2 + B^2 + \textcolor{red}{Mx}^2 + \textcolor{red}{ABo}^2}{2 \times \sqrt{\textcolor{red}{Mx}^2 + \textcolor{red}{ABo}^2}}) $$

$$ \textcolor{green}{\Psi} = arctan(\frac{\textcolor{red}{My}}{\textcolor{red}{Mz}}) - arcsin(\frac{L}{\sqrt{\textcolor{red}{Mz}^2 + \textcolor{red}{My}^2}}) $$

These equations correspond to the inverse equations, they allow to find the angles of the leg by knowing the X, Y, Z positions.

Unfortunately I was not able to find the Phi angle equation. I tried the other equations with numerical values and the results seem inconsistent.

## Next

I will have to re-study these equations as they seem to be incorrect.

<br>

# Week 15 - April 11, 2023 - 164h

## Construction of the robot support

In order to start our tests of the robot we had to hold it in the air. Thanks to that its legs don't touch the ground and we can make tests.

So I made a support to put it on.

I raised the robot of 40cm because at the maximum the legs are 30cm, that leaves us a margin not to touch the ground.

The robot rests on its plexiglass plate underneath. It rests on a wooden board that is the same size as its frame.

The whole support is made of wood. You can see it on the picture below

Robot support

<br>

## Next

The prototype of the leg being now finished, I would dedicate myself to the production of the three other legs during the next sessions.

<br>

# Week 17 - April 25, 2023 - 174h

Our prototype leg being finished and functional, it was now time to make the 3 other legs. So I concentrated on this part.

## 3D parts printing

Each leg requires many 3D printed parts. I used my personal printer to be able to print all these parts, this allowed us to save time and productivity. So we had these parts to print:

- 2 shoulder boxes (10:22 printing time each) 
- 3 complete reducers (7h48 of printing each)
- All the parts used for the articulations of the leg (9h12 of printing)

That is to say a total, when the printing goes well, of 53h20 of printing per leg. We still had to print some extra parts because it happened that some prints failed.

<br>

## Plexiglass cutting

To save time, the legs are made of plexiglass. So we had to cut the plexiglass plates with a laser cutter.

There was a total of 12 pieces to cut, for one leg :

- 1 tibia
- 2 thighs
- 1 support plate for the motors

parts list

cutting parts

After cutting the tibia, I had to drill them with a dremel in their length to be able to put screws to hold the straps.

tibia holes

<br>

## Next

Now that we have all the parts we will concentrate on the assembly of the legs and the reducers.

<br>

# Week 18 - May 2, 2023 - 208h

During the previous session, we had printed and cut out all the necessary parts to make the 4 legs. We then assembled all these pieces to make the legs.

## Reducers

We had to assemble the 9 remaining gearboxes. I cut and machined the steel rods that will be used as the output shaft of the gearbox. I had to take the right dimensions and then cut a false flat to be able to fit it in the gearbox with a screw as explained in [Report No. 11](https://github.com/RonanLc/Snoopytech/blob/main/doc/Rapports/Reports%20-%20Ronan%20Le%20Corronc/Session_11.md).

reducers axes

Once this was done I had to trim the 3D printed parts. When a part is printed in 3D the first layers are more crushed according to the height of the plate. They are therefore wider and the reducer being designed to the nearest millimeter, these wider layers pose a problem during assembly. I had to cut them on each piece to assemble the gearbox correctly.

After that I was able to add the bearings in the parts with a press (not having a press available I used a large pliers). Then I installed the steel axle.

I then gave the different parts to Maximilien so that he could grease the gears and close them permanently.

reducer work table

<br>

## Next

We were able to assemble the legs during our personal time and then install the legs on the chassis. We were able to have a fully assembled robot to finish this project.

Final robot picture

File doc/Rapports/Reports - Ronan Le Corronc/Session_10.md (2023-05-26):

# Week 3 - January 16, 2023 - 106h

## Modification of the gearbox

The gearboxes have been completely modified.

I changed a lot of insertitude to have a functional system and to do some tests. There is now some play between the gears but it is a play that we can correct as we go along.

The whole gearbox has also been printed in PLA instead of resin. The goal was to print a gearbox as quickly as possible and therefore not to bother with the resin.

The fixations of the gearbox have also changed. Instead of having two small screws holding the whole thing I installed 4 M4 screws on both sides to hold it firmly.

Gearboxs

<br>

## Prototype of a leg

For the presentation of Monday January 16th we wanted to present a functional paw. Due to lack of time I focused on one joint, the knee. So I made a prototype of the paw by modifying some parts to make only the knee move.

The reducer was fixed to the hip as if below.

Hips

<br>

## Transmission

The gearbox is not the only part of the transmission and speed reduction. There is another reducer thanks to a belt. Here for the knee, this reduction is done between the two plates of the leg corresponding to the thigh.

A steel pulley of 12 teeth is connected to the axis of the reducer. Then, another pulley of 66 teeth is connected to the part of the leg corresponding to the tibia.

I installed a belt between the two to connect them. This belt is not closed, its end is aimed at the tibia, it goes around the pulley of 12 teeth and then returns to screw in the tibia.

The tibia has therefore been modified to make room for the belt. The axis of the tibia is no longer aligned with the axis of rotation of the knee.

tibia

tibia

<br>

## Construction

All the pieces were cut and assembled.

You can find some videos here below.

[Testing the PLA planetary gearbox](https://youtu.be/Rsbbrvysg-4)

[Installation of the knee belt](https://youtu.be/3-rBXzxxJk4)

[How the gearbox works](https://youtu.be/zriuFQDhgsk)

The knee could be correctly assembled and we could make the tests of the functioning. It moved corrector in both directions.

The test can be seen [here](https://youtu.be/JdPR6T-Bgfs).

I purposely left the sound on to hear the reducer. It is very noisy, this is due to the play between the gears and also to the fact that I have not yet put any grease or oil to lubricate the gearbox. This will be added later.

## Next

It remains now to build the rest of the leg, the hip joint. Then to correct as much as possible the play in the reducer.

<br>

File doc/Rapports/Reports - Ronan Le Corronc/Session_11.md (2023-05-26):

# Week 5 - January 31, 2023 - 114h

## Modification of the gearboxes

A first problem on the reducers was encountered during the first tests : the paste did not always follow the movement of the motor. It was getting out of sync with the gearbox.

And there is a simple reason, the steel shaft controlling the belt was slipping in the gearbox.

Reducer V1

As shown on the picture, the axle was only sliding in the part that was supposed to drive the movement of the lug and so it was sliding when the system was asking for the least torque.

I changed this so that the two parts stay well linked during the movements.

I simply cut a flat on the axis and added a nut with a screw inside the part.

Reducer V2

After retesting, this solution solved the problems of slippage and play. The system is now solid and resists high torque.

<br>

## Resizing of parts

The previously modified part is at the heart of the reducer. Since it has been enlarged to accommodate the life in its thickness. I had to modify all the other parts of the system so that it doesn't create an offset.

I also modified the shoulder modeled by Maximilien so that it could match the new dimensions of the reducers.

Leg assembly

<br>

## Problem with the belts

We encountered a problem during the new tests. When we apply a high torque to the system the belt jumps and does not transmit the motion.

We discovered that the reason was that the belt was not tight enough. The belt is connected with screws on both ends. It was difficult to tighten it when we aimed the screws.

So I added a system on the thigh of the robot allowing to tension the belt with a screw.

Belt tensioner

Belt tensioner schematic

The lower part of the tensioner will come against the belt and therefore will tension it. We can adjust the tension with the screw (in yellow on the schematic) then a screw passing through the hole of the blue part will lock the position of the tensioner.

The system is a first version and may need to be improved. It is possible that the friction of the tensioner with the belt due to the tension is too high. In this case it will be necessary to install a bearing.

<br>

## Next

We still have to add the potentiometers on the joints. Then we will be able to print the whole robot.

<br>

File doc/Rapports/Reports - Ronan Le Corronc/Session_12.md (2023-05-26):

# Week 6 - February 7, 2023 - 122h

## Installation of the potentiometers

We now had to install the potentiometers within the system to be able to have a feedback on the position of the joints.

The main difficulties were to design simple, reliable systems with as little change as possible in the design of the robot.

Maximilien Kulbicki took care of the hip joint and I took care of the knee and shoulder joints.

### **1 - The knee**

For the knee, I dismantled the potentiometers to keep only two pieces. This allowed to save a lot of space because the potentiometers were very imposing.

The two parts are a fixed part, having the tracks (the brown part) and a mobile part making the contact between these tracks (the white part).

pot knee

So I used the steel axis of the joint. This one will be fixed to the tibia and will turn if we move this joint. I fixed the mobile part to it.

And with the help of a 3D printed part I could connect the fixed part to the thigh. These two parts will vary according to the movement and we can know the position.

To connect the axle to the mobile part, I wanted to drill the axle in its length and come to tarod it. Because of the lack of material, the operation seemed complicated. Pascal Masson helped me to find a solution and succeeded in cutting the axis so that it could be assembled directly.

Steel axis

### **2 - The soulder**

For the shoulder I used the same two pieces of the potentiometer. I positioned the mobile part on the shoulder shell and the fixed part on the frame.

pot shoulder

The mobile part will be through a carbon tube that will be fixed to the bearing of the shoulder shell.

The fixed part will be attached to a 3D printed part that will be fixed inside the carbon tube.

<br>

## Assemblage de l'épaule

After finishing the potentiometers and correcting the last errors. We were able to start prototyping a leg.

I printed a version of the shell in a beautiful color and assembled the different components inside.

montage 1

montage 2

montage 3

The parts fit together perfectly and the system has very little play for the moment.

It remains however to print a gearbox and re-cut the steel axes of the system.

<br>

## Next

The goal is to have a prototype of leg before the next vacations. I think it's possible.

We only have to print a gearbox, cut the steel axles, then make the final assembly with the belts.

<br>

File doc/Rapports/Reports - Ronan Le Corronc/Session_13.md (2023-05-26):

# Week 7 - February 14, 2023 - 128h

## Printing the reducer

We were missing a reducer to finish the leg, so I printed it in PLA and assembled it.

Some parts had a printing problem so I had to go back twice.

We had enough bearings to make two so the gearbox was almost complete, it just lacked the steel shaft for the output rotation.

Reducer

<br>

## the assembly of the knee

The knee is composed of two main parts:

- one that we will consider fixed here, it is composed of the two plates of the thighs, the external protections and the potentiometer.

leg part 1

- the second one which is mobile, it is composed of the tibia, the steel axis and the second part of the potentiometer.

leg part 1

I had to re-cut the plexiglass plate of the second part. I also had to find a solution to fix the steel axis to the plexiglass plate.

So I chose to use the same technique used in [the reducers](https://github.com/RonanLc/Snoopytech/blob/main/doc/Rapports/Reports%20-%20Ronan%20Le%20Corronc/Session_11.md). I drilled the plate in its length and came to screw in a screw pressing on the rod.

axis fixation

I also soldered 3 wires on the potentiometer to allow to get the position of the potentiometer.

We tested the values it returns but we have a problem with it, it only works on a certain range then returns 0 afterwards. I suspect that the potentiometer track was scratched during disassembly or assembly. We will have to correct this problem.

The leg is fully assembled and fits perfectly with the shoulder.

Maximilien took care of re-cutting the axles for the reducers and so we will be able to connect all the systems together with the belts.

System picture

<br>

## Next

The goal is now to make the first tests of movement with the leg and torque tests.

After that we will be able to focus on the position control of the leg and the production of the 3 other legs!

<br>

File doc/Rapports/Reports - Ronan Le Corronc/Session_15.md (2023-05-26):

# Week 10 - March 7, 2023 - 136h

## Communication in Nvidia Jeston nano and Arduino UNO

The goal here is to be able to communicate between the two boards. 

The Arduino board will be used as a low level board, it will apply the commands of the Nvidia and will control the different sensors and motors.
The Nvidia card will be used to perform all the calculations and data analysis to determine the movements of the robot.

The two cards must be able to communicate with each other without stopping.

both card

<br>

## Wiring

The wiring is quite simple, you just have to connect the RX of the arduino to the TX of the Nvidia. Then connect the RX of the Nvidia to the TX of the arduino.

But when I looked a little bit more closely, I noticed a problem. The serial communication of the Nvidia works in 3.3V unlike the arduino which works in 5V. In the direction Nvidia -> Arduino, this is not a problem, the arduino will be able to read the bits received in 3.3V. But in the opposite direction you have to lower the voltage, the 5V can damage the Nvidia card.

I thought at first to use only a voltage divider bridge. But according to my research, it works very well at low frequency, but by increasing the communication speed, we risk to lose a lot of bits.

The solution was to add a level shifter, a small component designed for this use allowing to communicate with two different voltages.

So the wiring is like this:

Wiring

<br>

## Programming

The code is composed of two scripts, one in C that is run on the arduino and one in Python run on the Nvidia.

The ``Python`` code is as follows:

```Arduino
void setup(){
  Serial.begin(115200);
  while(!Serial){;}
}

const char stopPoint = '|';

void loop(){

  if (Serial.available()>0) {

    String commandFromJetson = Serial.readStringUntil(stopPoint);

    String ackMsg = "Message :" + commandFromJetson;

    Serial.print(ackMsg);
  }
  
  delay(500);
}
```

Here the code is only designed to receive a message from the serial communication and display it on the serial monitor.

The ``Python`` code is as follows:

```Python
import serial
import time

#arduino = serial.Serial('/dev/ttyAcM0', 115200, timeout=5)

arduino = serial.Serial(
port = '/dev/ttyACM0',
baudrate = 115200,
byterate = serial.EIGHTBITS,
parity = serial.PARITY_NONE,
stopbits = serial.STOPBITS_ONE,
timeout = 5,
xonxoff = False,
rtscts = False,
dsrdtr = False,
writeTimeout = 2)

while True:
    try:
        arduino.write("Command from Jetson|".encode())
        data = arduino.readline().decode()
        if data:
            print(data)
        time.sleep(1)
    except Exception as e:
        print(e)
        arduino.close()
```

This code is designed to first set the communication port and then, if everything works well, send the data to the arduino via the serial link. I use the ``serial`` library for that.

<br>

## Next

For the moment the communication works only by connecting the Arduino board in USB to the Nvidia. The Nvidia board has only one USB port which is already used for the camera, so we have to free it by using the RX/TX pins. Unfortunately the communication does not work via these ports. The problem seems to come from the port declaration in the Python script, the port used is not the right one.

So I will have to find the right port and redo some tests to have a reliable and functional communication.

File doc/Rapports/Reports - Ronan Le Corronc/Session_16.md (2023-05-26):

# Week 11 - March 13, 2023 - 140h

During this session I concentrated on printing parts. The robot's paste being soon finished, we have to print all the parts to be able to build the three others quickly.

So I printed some parts that were already working.

## Gearbox

reducer

<br>

## ESC bed

ESC bed stack

ESC bed empty

ESC bed full

The ESC beds are not very strong though. They bend when I hang all the ESCs on them, so I would have to modify them to fit more rigidly.

<br>

## Shoulder case

Shoulder close

Shoulder open

The shoulders had to be reprinted many times because a lot of movements take place inside, we encountered many conflicts.

<br>

## Next

I continue to print parts as soon as possible and modify them when necessary to finish the robot as soon as possible.

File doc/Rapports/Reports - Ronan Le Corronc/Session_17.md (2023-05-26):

# Week 12 - March 21, 2023 - 143h

During this session I focused on the laser cut parts. I modified the tibia by removing the 3D printed part at the strap. So we have only one piece in plexiglass which is much more resistant.

tibia 3D

tibia

I was also able to help Maximilien to make the body of the robot, so we cut the many plexiglass plates. Printed the parts allowing the assembly. And made a first assembly of the body.

Body view

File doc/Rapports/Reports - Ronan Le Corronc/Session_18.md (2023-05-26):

# Week 13 - March 28, 2023 - 149h

During this session I focused on the kinematic study of the robot. As explained in [Report No. 14](https://github.com/RonanLc/Snoopytech/blob/main/doc/Rapports/Reports%20-%20Ronan%20Le%20Corronc/Session_14.md) we have to find the mathematical formulas allowing to pass from an orthonormal reference X Y Z to the angles of the leg.

I decided to start over because my previous calculations were underdeveloped and wrong.

## Schematics and name

For these calculations I used the following notations and diagrams:

schematics

**Mx**, **My**, **Mz** correspond to the desired X, Y, Z displacement.

<br>

## Direct equations

So I was able to determine the following equations:

$$ AB^2 = A^2 + B^2 - 2 \times A \times B \times cos(\textcolor{green}{\Theta}) $$

$$ \textcolor{red}{Mx} \text{ = L } \times \text{cos(} \textcolor{green}{\Psi} \text{) + AB } \times \text{cos(} \textcolor{green}{\Phi} \text{ - arcsin(} \frac{A \times sin(\textcolor{green}{\Theta})}{AB} \text{))} \times \text{sin(} \textcolor{green}{\Psi} \text{)} $$

$$ \textcolor{red}{My} \text{ = L } \times \text{sin(} \textcolor{green}{- \Psi} \text{) + AB } \times \text{cos(} \textcolor{green}{\Phi} \text{ - arcsin(} \frac{A \times sin(\textcolor{green}{\Theta})}{AB} \text{))} \times \text{cos(} \textcolor{green}{\Psi} \text{)} $$

$$ \textcolor{red}{Mz} \text{ = AB } \times \text{sin(} \textcolor{green}{\Phi} \text{ - arcsin(} \frac{A \times sin(\textcolor{green}{\Theta})}{AB} \text{))} $$

These equations correspond to the direct equations, they allow to obtain the X, Y, Z positions by knowing the angles of the robot legs.

## Next

I will focus on the inverse equations, the ones that allow to find the angles of the leg by knowing the X, Y, Z positions.

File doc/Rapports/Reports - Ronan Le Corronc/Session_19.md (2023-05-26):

# Week 14 - April 4, 2023 - 155h

I determined last week the direct equations, so now I have to find the inverse equations.

To do this I based myself on the same diagrams.

schematics

## Inverse equations

So I was able to determine the following equations :

$$\textcolor{red}{ABo} = AB \times cos(\textcolor{green}{\Phi} - arcsin( \frac{A \times sin(\textcolor{green}{\Theta})}{AB}))$$

$$ \textcolor{green}{\Theta} = arccos( \frac{A^2 + B^2 + \textcolor{red}{Mx}^2 + \textcolor{red}{ABo}^2}{2 \times \sqrt{\textcolor{red}{Mx}^2 + \textcolor{red}{ABo}^2}}) $$

$$ \textcolor{green}{\Psi} = arctan(\frac{\textcolor{red}{My}}{\textcolor{red}{Mz}}) - arcsin(\frac{L}{\sqrt{\textcolor{red}{Mz}^2 + \textcolor{red}{My}^2}}) $$

These equations correspond to the inverse equations, they allow to find the angles of the leg by knowing the X, Y, Z positions.

Unfortunately I was not able to find the Phi angle equation. I tried the other equations with numerical values and the results seem inconsistent.

## Next

I will have to re-study these equations as they seem to be incorrect.

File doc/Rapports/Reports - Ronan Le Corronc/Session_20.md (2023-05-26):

# Week 15 - April 11, 2023 - 164h

## Construction of the robot support

In order to start our tests of the robot we had to hold it in the air. Thanks to that its legs don't touch the ground and we can make tests.

So I made a support to put it on.

I raised the robot of 40cm because at the maximum the legs are 30cm, that leaves us a margin not to touch the ground.

The robot rests on its plexiglass plate underneath. It rests on a wooden board that is the same size as its frame.

The whole support is made of wood. You can see it on the picture below

Robot support

<br>

## Next

The prototype of the leg being now finished, I would dedicate myself to the production of the three other legs during the next sessions.

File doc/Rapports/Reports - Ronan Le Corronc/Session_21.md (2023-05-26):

# Week 17 - April 25, 2023 - 174h

Our prototype leg being finished and functional, it was now time to make the 3 other legs. So I concentrated on this part.

## 3D parts printing

Each leg requires many 3D printed parts. I used my personal printer to be able to print all these parts, this allowed us to save time and productivity. So we had these parts to print:

- 2 shoulder boxes (10:22 printing time each) 
- 3 complete reducers (7h48 of printing each)
- All the parts used for the articulations of the leg (9h12 of printing)

That is to say a total, when the printing goes well, of 53h20 of printing per leg. We still had to print some extra parts because it happened that some prints failed.

<br>

## Plexiglass cutting

To save time, the legs are made of plexiglass. So we had to cut the plexiglass plates with a laser cutter.

There was a total of 12 pieces to cut, for one leg :

- 1 tibia
- 2 thighs
- 1 support plate for the motors

parts list

cutting parts

After cutting the tibia, I had to drill them with a dremel in their length to be able to put screws to hold the straps.

tibia holes

<br>

## Next

Now that we have all the parts we will concentrate on the assembly of the legs and the reducers.

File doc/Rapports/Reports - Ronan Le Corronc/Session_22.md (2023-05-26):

# Week 18 - May 2, 2023 - 208h

During the previous session, we had printed and cut out all the necessary parts to make the 4 legs. We then assembled all these pieces to make the legs.

## Reducers

We had to assemble the 9 remaining gearboxes. I cut and machined the steel rods that will be used as the output shaft of the gearbox. I had to take the right dimensions and then cut a false flat to be able to fit it in the gearbox with a screw as explained in [Report No. 11](https://github.com/RonanLc/Snoopytech/blob/main/doc/Rapports/Reports%20-%20Ronan%20Le%20Corronc/Session_11.md).

reducers axes

Once this was done I had to trim the 3D printed parts. When a part is printed in 3D the first layers are more crushed according to the height of the plate. They are therefore wider and the reducer being designed to the nearest millimeter, these wider layers pose a problem during assembly. I had to cut them on each piece to assemble the gearbox correctly.

After that I was able to add the bearings in the parts with a press (not having a press available I used a large pliers). Then I installed the steel axle.

I then gave the different parts to Maximilien so that he could grease the gears and close them permanently.

reducer work table

<br>

## Next

We were able to assemble the legs during our personal time and then install the legs on the chassis. We were able to have a fully assembled robot to finish this project.

Final robot picture

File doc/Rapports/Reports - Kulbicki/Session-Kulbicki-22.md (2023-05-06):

# Worksession 22 - 02/05/2023

## Overview 

During this session, my work was focused on the building of the legs of the robot. 

## Manufacturing 

Having all the necessary elements to assemble the four legs, I proceded to do so. 

pattes

The motor-reducers of each leg needed to be grease in order to obtain silent motors.
I also shared the soldering of the mouthpiece of the motors and ESCs with Ronan. 

Furthermore, I have decided to cut the ESC beds in plexiglass in reason of the higher speed of production compared to 3D printing. 
The result is solid and easily supports an ESC. 

esc

## Remaining tasks

The connexion of all the ESC to the power supply still remains undone and the legs haven't been mounted to the body yet. 
The code implementing the math hasn't been written yet.

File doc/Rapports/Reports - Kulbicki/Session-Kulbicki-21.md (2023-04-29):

# Worksession 21 - 25/04/2023

## Overview

During this session, I mainly machined the pieces needed in the leg assembly. 

## Machining 

We have started the assembling of the four legs. This assembly requieres many machined elements such as metal rodes, carbon fiber tubes or plexiglass. 
I proceded to cut the metal rodes used for the four axis for each leg.

The length for each rod is :

    knee rod : 25mm (6mm diameter)
    hip rods : 46mm and 76mm (5mm diameter)
    shoulder rod : 35mm

Thus, we have a total of 12 rods that are currently being installed in the motor reducers and knee. 

Furthermore, I continued with the cutting/drilling of the carbon fiber tubes responsible for the hip and shoulder movement. 
This task was easily done with the template built at the [session 10](https://github.com/RonanLc/Snoopytech/blob/main/doc/Rapports/Reports%20-%20Kulbicki/Session-Kulbicki-10.md).

We now have an amount of 7 tubes that are ready to be mounted (3 hip axis + 3 shoudler axis + 1 large shoudler axis).

Finally, I have greased the available motor reducers. 

## Angle computation implementation 

The math study led last week needs some testing to see how accurate it is. 

Therefore, I have written a small program that calculates the position of a leg given the angles of its joints and vice versa.

I have tried to compute the position for the respective angles : 

    phi = 10°
    theta = 45°
    psi = 90°

The output of the function is :

    mx = 6.65 mm
    my = 111.6 mm
    mz = 218 mm
    mz' = 202.32 mm

I have then tried feeding these values in the function calcultating the angles given the position and the output is :

    phi = -10°
    theta = -48°
    psi = 89° 

As seen, the function computes with at least a 3° precision. 
I haven't figured out yet the cause of the negative sign in front of the phi and theta angles. 
I must pursue the testing of this program.

## Next week's session

For next week's final session, I will have to finish mounting the legs.
I must also program a short class allowing to easily control the movement of an entire leg based on a given position to achieve. 
This program will contain portions of the program I have testing during this session.

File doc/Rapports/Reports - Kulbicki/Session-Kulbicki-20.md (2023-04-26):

# **Worksession 20 - 11/04/2023**

## **Overview** 

During this session, my work was focused on the math responsible for the calculation of the knee, hip and shoulder angles.

## **Representation and goals**

### **Coordinate system**

The leg of the robot can be represented in a Cartesian coordinate system $(xyz)$ in which two plans are enough to describ the entire leg. 
The lower leg can be represented in the $(x0z)$ plane, whereas the shoulder is set in the $(z0y)$ plane. 

The following pictures give a simple representation of the leg in its planes :





As shown on the pictures, the leg's position in this coordonate system is represented by a vector $(OC)$ whose coordinates are $(M_x,M_y,M_z)$.
The points can be described as so :

    O : the intersection between the shoulder's revolution axis and the hip's revolution axis (projected on the (zOy) plane)
    A : the hip joint
    B : the knee joint
    C : the feet 
    A' : the projection of A on the (zOy) plane
    Mz' : the height of the leg based on the given shoulder inclination

The angles we can act on are :

    phi : angle between the higher leg (AB) and lower leg (BC)
    theta : angle between the reference (shoulder) and the higher leg (AB)
    psi : inclination of the shoulder 

### **Inputs and outputs** 

The only data we can feed to our motor are the angles $(\phi,\theta,\psi)$. 

At the end of this study, we should be able to input the requested position of our leg $(M_x,M_y,M_z)$ and retrieve the angles allowing this position.

## **Higher and lower leg study**

In this study, I won't develop much its progress but rather the theorems and relations allowing to obtain the results. 



In the first picture shown above, we have a representation of the problem and its different parameters.
The goal is to expose all the relations between the different unknows $(\theta,\psi,M_x,M_z)$. 
The lengths $(AB)$ and $(BC)$ are known as the real length of the robot's leg. 

Using basic trigonometry, we are able to express $M_x$ and $M_z$ as a function of $\theta$ and $\psi$ :

$$M_z = AB \times sin(\theta) + BC\times sin(\psi - \theta)$$
$$M_x = BC\times cos(\psi -\theta) - AB\times cos(\theta)$$

These formulas can be useful given that we know the angles but need the position.

Again, using simple trigonometric relations and [Al Kashi's theorem](https://fr.wikipedia.org/wiki/Loi_des_cosinus) on the generalized Pythagoras theorem, 
we are able to express $\theta$ and $\psi$ knowing the position $M_x$ and $M_z$ :

$$\psi = arccos(\dfrac{AB^2 + BC² - {M_x}² - {M_z}²}{2\times AB\times BC })$$

1. Case where Mx is positive (or zero)

$$\theta = \pi - arccos(\dfrac{AB² + AC² - BC²}{2\times AB\times AC}) -arctan(\dfrac{M_z}{M_x}) $$

2. Case where Mx is negative 

$$\theta = arctan(\dfrac{M_z}{M_x})- arccos(\dfrac{AB² + AC² - BC²}{2\times AB\times AC})  $$

with $AC = \sqrt{M_x² + M_Z²}$.

### **Conditions to respect** 

To allow these formulas to be effective on our leg, we must ensure the follwing conditions are respected :
$$Mz < AB + BC$$
$$|Mx| < AB + BC$$
$$Mz > 0$$

We must also ensure that the angles $\theta$ and $\psi$ are restricted to the potentiometers limits angles. 

## **Shoulder inclination study**



The previous picture exposes the problem and all its unknows. 
In this study, the aim is to obtain the relations between the different unknows $(\phi,M_z,M_y,M'_z)$.

Using basic trigonometry, we are able to express $M'_z$ and $M_y$ as functions of $\phi$ :

$$M'_z = M_z \times cos(\phi) - OA' \times sin(\phi)$$
$$M_y = OA' \times cos(\phi) + M_z \times sin(\phi)$$

These formulas can be useful given that we know the angles but need the position.

Again, using simple trigonometric relations and Al Kashi's theorem on the generalized Pythagoras theorem, 
we are able to express $\phi$ knowing the position $M'_z$, $M_y$ (and $M_z$) :

$$\phi = \frac{\pi}{2}  - arccos(\frac{{OA'}² + M_y² + {M'}_z² - M_z²}{2\times OA' \times \sqrt{M_y² + {M'}_z²}}) - arctan(\frac{M_y}{{M'}_z})$$

### **Conditions to respect** 

The formula describing $\phi$ is valid if the following conditions are respected :

$${M'}_z² + M_y² = {OA'}² + M_z²$$ 

- in order for $\phi$ to be negative (below the reference), these two conditions must be respected :
$$M_y < M'_z$$ 
and
$$M_z² > OC² + {OA'}² - \sqrt{2} \times OA' \times OC$$
with $OC=\sqrt{M_y² + {M'}_z²}$.

The <ins>**first condition is crucial**</ins> if we want a precise $M'_z$ and $M_y$ position since it describes how should $M_z$ behave in order for the foot to touch the ground. 

## Tests 

I computed a few tests with the given $(M'_z,M_y,M_x,M_z,AB,BC,OA')$ values and drew some of the results. 
The result are satisfying and allow to express $(\phi,\theta,\psi)$ precisely. 

## Next week's objective 

For next week's session, I will try to implement these formulas in a simple code to test its efficiency.
I will also have to start manufacturing new legs for the robot.

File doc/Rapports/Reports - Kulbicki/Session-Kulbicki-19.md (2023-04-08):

# Worksession 19 - 04/04/2023

## Overview 

This session was centered around resolving the issues mentionned last week and setting the offsets and limits of each potentiometer.

## Manufacturing

The shoulder shell of the robot's leg had to be changed since the screw maintening the belt in the hip was conflicting with the previous shell.
Once the shell was switched, I put the hip in motion and no conflicts could be noticed. 
I also put the other joints in motion to know if they were operational for the motor servo class ```MotorJoint```.

## Servo parameters

Before applying the ```MotorJoint``` code on the leg to precisely drive it, parameters have to be set for each joint.
These parameters gather :

    The minimum angle the joint can reach.
    The maximum angle the joint can reach.
    The virtual 0° angle, used has a reference in the kinectic study lead by Ronan.
    The direction to go from the minimum angle to the maximum. Takes the value -1 if the motor has to turn anticlockwise to go from min to max. Takes the value 1 otherwise. 

For each parameter, the motor must be put in motion and by changing the rotation speed we are able to determinate which position for the joint corresponds to which parameter. Obvisouly, the parameters for each leg will depend on its assembly.

I collected all this data and here are the results :

    Knee joint : [min,max]=[26-178]°; ref=170°; direction d=-1.
    Hip joint : [min,max]=[60,160]°; ref=145°; d=-1.
    Shoulder joint : [min,max]=[11,164]°; ref=100°; d=1.

After plugging in these values in the [main](https://github.com/RonanLc/Snoopytech/blob/main/code/src/main.cpp) program, I tested the servo driving class on each joint with the PID correctionnal values (kp=0.75, kd=0.33). 

At first, I tried getting each joint to go from one angle to another slowly. They all succeed without any rebounds or rough movement.
Then, I applied a small resistance (500g) on each joint as it was in motion. Most of the belts ripped off as the motor's speed quickly approached its maximum. 
I didn't forsee this behaviour and thus didn't expect the belt from rippig. 

I will have to change the belts and continue the testing and figure out why belts ripped.

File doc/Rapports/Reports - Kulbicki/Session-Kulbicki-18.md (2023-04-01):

# Worksession 18 - 28/03/2023

## Overview 

During this session, I worked on the body of the robot. 

## Assembling and machining 

The goal of this session was to implement the new potentiometers in the body of the robot. 
I began by soldering cables to these potentiometers. The smooth metal surface of the potentiometer needs to be scratched in order for the soldering to be effective. 
The potentiometers return proper analogic values and their angle range is about [0°-240°] +- 5°. 

I used super glue to attach the potentiometer return the hip angle and put the hip in motion to see the quality of the gear moving the potentiometer.
This can be seen in the following video :

[Link](https://youtube.com/shorts/3UBivNCR2bs?feature=share)

I also glued the key that is plugged in the potentiometer of the shoulder and assembled the {key+potentiometer} in the carbon fiber tube maintening the shoudler.
The result can be seen in the next video :

[Link](https://youtube.com/shorts/v6eRysPjnHw?feature=share)

The carbon fiber tubes had to be drilled in order to attach the socket of the potentiometer.

To reduce the noise emitted by the motor-reducers, I filled them with synthetic grease. 

Once all the motor-reducers were greased, the potentiometers ready to be installed, I proceded to the assembling of the leg. 
This phase took about two hours due to the amount of requiered pieces. The most time consuming task came from all the screwing needed.

The following picture shows the assembled leg, with its new potentiometers :



I then continued with the dissassembing of the body in order to install the leg and link it to its third motor-reducer (the one aboard the body).
The mounted leg can be seen on the floowing pictures :

unnamed



## Short motion tests

The following videos show each joint's motion :

[Knee_motion](https://youtu.be/SUaDrIiHGKA)

[Hip_motion](https://youtu.be/5ANu7j0sUI8)

[Shoulder_motion](https://youtu.be/d3nsmIFnhjQ)

As we can see, the knee and the hip joints move freely whereas the shoudler joint struggles
This comes from the belt not being tense enough. 

Furthermore, as seen on the second video, the shoulder structure has been cut and opened by hand near the bearing putting the hip in motion.
It had to be done since I forgot to consider the screw maintening the belt in the bearing while conceiving the shoulder's structure. 
The hole prevents the screw from conflicting with the shoulder shell.

I have resolved this issue by increasing the inner diameter where the screw was conflicting on the shoulder shell 3D file. 

## Next week's objective 

For next week's session, I will attempt to solve the previously mentionned issue.
Once all the issue have been delt with, I will proceed to adjust the offsets for each potentiometer in the ````MotorJoint``` code.

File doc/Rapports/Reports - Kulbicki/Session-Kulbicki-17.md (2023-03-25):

# Worksession 17 - 21/03/2023

## Overview 

During this short session I worked on the body of the robot.

# Machining 

I began this session by dismantling the body of the robot to change the old shoulder with the new version.
This version includes supports for the new potentiometers we received.

Unfortunately, while taking the shoudler apart, I broke two of the vertical frames holding the carbon tubes.
These frames broke for a quaint reason being that I cut them in a plexiglass sheet that had already been used and was partially cut.
This means that integrity of the frames was compromised.

I proceded to cut new frames in brand new plexiglass, preventing the same mistake from happening.

New metal rodes also needed to be cut and shaped for the potentiometer's mouthpiece.

I now have all the necessary pieces to assemble an entire leg on the body, I might just need to drill a few holes in the carbon tubes to screw the potentiometer's housing.

## Next week's objective

Once the whole leg with the three potentiometers are mounted, I will code a simple program to test the mobility of each joint.

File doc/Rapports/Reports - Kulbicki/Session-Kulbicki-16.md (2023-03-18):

# Worksession 16 - 13/03/2023

## Overview 

This session was mainly centered around the making and the building of the body.

## Building 

I rebuilt the body of the robot with the new versions of the pieces (described in the [Session 11]() and [Session 12]()).
I cut out the frames and planes parts in plexiglass. 
These pieces are :
 
    2 motor-axis-anchoring frames
    4 motor frames
    2 lining frames
    1 frame with holes for the camera mounts
    1 frame with holes for the Jetson Nano
    2 chassis plates

Furthermore, I launched 3D prints of the following pieces :

    4 ESC bed spacers 
    1 ESC bed 
    4 square maintening the frames together
    1 whole motor reducer
    1 entire shoulder

Once all the pieces were made, I proceded to the assembly of the body.

The result of the assembly is seen on the following pictures :




## Review of the build

All the frames fit perfectly in their respective slots. 
The supports for the tube let the carbon tubes slide in without being loose. 
Screwing the frames and the squares onto the frames is time consuming but with the right tools can be done easily. 
The frame holding the motor is slightly loose and lets the motor move sideways. This could be corrected by increasing slightly the thickness of the frame.
The camera mount can be assembled with ease on the body.
The leg of the robot does not requiere any screwing to be mounted. The carbon fiber tubes simply need to be inserted in the leg's bearing. 
The holes of the frame holding the axis of the motor are too wide, resulting in the bearings sliding out of them. 

## Next week's objective 

For next week's session, I will attend to hook up the third motor onto the leg. This underlines that I will need to find a (temporarely) solution for the potentiometer.

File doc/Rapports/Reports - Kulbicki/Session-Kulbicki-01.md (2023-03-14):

# Séance 1 - 14/10/2022
## Travail réalisé

Lors de cette première séance je me suis chargé de la modélisation du corps de notre robot sur Fusion360.
En suivant les plans que nous avions fixés avec Ronan, j'ai modélisé plusieurs pièces:
- la plaque de support à laquelle viendront se fixer les composants
- le cadre servant à maintenir les plaques de support et les tubes
- le tube autour duquel les pattes pivoteront
- des entretoises pour assurer la solidité du corps 
- des équerres pour éviter de perdre l'orthogonalité entre les plaques et les cadres

Resume

Les pièces en rose sont en plexiglass (plastique pmma). Les pièces en vert sont en fibre de carbone. Les pièces en bleu sont en PLA. Les pièces en jaune sont en acier.

J'ai associé les pièces vertes au granite car sa masse volumique est proche de celle de la fibre de carbone (qui n'est pas disponible sur fusion). La masse volumique du granite (2,7g/cm3) étant superieure à celle de la fibre de carbone (1,95g/cm3), on peut surévaluer la masse totale du corps à 1,16kg.

J'ai également fait de recherches sur les entretoises existantes sur le marché. Il nous faut des entretoises d'une longueur de 86mm, ce qui ne semble pas disponible à la vente. Il nous sera peut-être plus judicieux de les imprimer nous même. 

## Objectifs pour la prochaine séance
-  Poursuivre et assister Ronan dans la modélisation de certaines pièces des pattes (épaule, transmission..)

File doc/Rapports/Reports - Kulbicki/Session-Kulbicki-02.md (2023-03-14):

# Worksession 2 -17/10/2022

## Camera and ultrasound sensor

During this session, my work was focused on the recherch and the conception/design of a piece allowing our camera and ultrasound sensor to rotate at an angle of 180°. 
Each sensor will have its own support, which will use a servo motor SG-90 to rotate. 
Thus, I needed to design a support for the servo that makes its rotation axis the same as the support's swivel axis.
This allows to reduce the amount of transmissions between the motor and the swivel axis.

resume_2

All the designed parts will surely be 3D printed. 

## Force study

Furthermore, I got interested in the sturdiness and strength of the body of the robot.
So, I conducted a force study on the body thanks to Fusion360.
When applying a force described by a norm of 20N (the equivalent of a 2kg weight), vertical and directed towards the ground, on the frame of the body at the extremities of the tubes, no distorsions are to be seen. 

simulation_force

On the picture above, the colours close to blue reprensent an absence of distorions of the piece when put under stress. On the other side, the lighter colours represent a strong distorsion when the body undergoes stress.
Thereby, the body seems capable of withstanding the totale weight that it will be exposed to.

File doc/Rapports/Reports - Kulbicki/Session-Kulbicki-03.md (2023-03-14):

# Worksession 3 - 28/10/2022

## Motor and support

Over this session, I focused of the implementation of the brushless motors we will be using (ACK-5312CP).
I began by modeling it from the dimensions found on the merchant's website.

brushless

My next aim was to find a solution allowing us to link the motors to the body.
I started by sketching on paper ideas around a support to maintain the motor at a vertical position. This fisrt set of support will be used for
the motors that lead the shoulder of the leg.

equerre_support_moteur

The first support holds the motor by its foot, while the other holds it by its axe.
I haven't figure out yet if the support that holds the motor by the foot will be 3D printed or not, the other possibility being that we could 
make it in steel. In the case we make it in steel, we might not need a support for the motor's axe. 
Thus, I only modeled the support for the motor's foot, since the modeling for the axe is similar.

## Assembly

Finally, I attached the head designed last week to the body to get a first preview of the assembly.

assembly_head

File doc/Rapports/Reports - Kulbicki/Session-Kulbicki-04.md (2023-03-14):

# Worksession 4 - 15/11

This worksession was centered around the gyro sensor GY-521 and reajustments of the body of our robot. 

## **GY-521, gyro sensor**

### **Description**

The GY-521 sensor features a 3-axis gyroscope, a 3-axis accelerometer, a digital motion processor (DMP) and a temperature sensor. The DMP is used to process algorithms directly on the board. 

The GY-521 pin layout presents itself like this:

    VCC : 5V (recommended)
    GND
    SCL and SDA : Serial Clock/Data Line
    XCL and XDA : The sensor can act as the master of another sensor
    AD0 : changes the I2C adress of the board (LOW for 0x68; HIGH for 0x69)
    INT : interrupt digital output

The GY-521 uses an I2C Serial data bus to retrieve the raw sensor values. 

Most of the tutorials I found about this sensor don't use the DMP to process the raw values, given by the sensors, to stable position data.
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

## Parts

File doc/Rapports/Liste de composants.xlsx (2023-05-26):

Nom | Quantité | Prix | Prix total | Poids(g) | Lien | Description
Corps et pattes
Tube en fibre de carbone | 1 | 23.36 € | 23.36 € | 71 | https://fr.aliexpress.com/item/1005002248466483.html?curPageLogUid=nz516Ros1nuv | Color: 2pcs 30x28x500mm
Poulis | 12 | 1.11 € | 13.32 € |  | https://fr.aliexpress.com/item/1005002226516848.html?ad_pvid=202210180153269689169860306820006827501_2&s=p | diamètre d'alésage 12 teeth Bore 5mm ; largeur 6mm
Fixation courroie | 1 | 3.35 € | 3.35 € |  | Maecoom 10/20pcs 3D Imprimante Pièces GT2 Ouvert Ceinture Clip Ouvert fin Courroies Ceinture pince À Sertir | AliExpress (https://fr.aliexpress.com/item/1005003144053397.html?_randl_currency=EUR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) | Taille: 20 pcs
Courroie | 1 | 3.32 € | 3.32 € |  | https://fr.aliexpress.com/item/10000115962505.html?_randl_currency=EUR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 | Largeur 6mm; longueur 5m
Roulement | 1 | 3.46 € | 3.46 € |  | https://fr.aliexpress.com/item/33006573082.html?_randl_currency=EUR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 | Longueur MR106ZZ /!\
Roulement | 1 | 3.46 € | 3.46 € |  | https://fr.aliexpress.com/item/33006573082.html?_randl_currency=EUR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 | Longueur: MR85ZZ /!\
Roulement | 12 | 0.95 € | 11.40 € | 5 | https://fr.aliexpress.com/item/32997948364.html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
Motorisation
Brushless ACK-5312CP | 2 | 116.43 € | 232.86 € | 80 | https://fr.aliexpress.com/item/33027613653.html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 | Couleur: 6pcs 5010 360KV
ESC 40A | 12 | 14.06 € | 168.72 € | 132.8 | ZMR – ESC bidirectionnel sans balais 12A/20A/30A/40A/50A/60A/80A, pour voiture télécommandée, hélice sous marine pneumatique | AliExpress (https://fr.aliexpress.com/item/1005003569012758.html?_randl_currency=EUR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) | Couleur: 40A (2-6S)
Capteurs
youyeetoo Slamtec RP LIDAR | 1 | 109.99 € | 109.99 € | 363 | https://www.amazon.fr/Scanradius-LIDAR-Sensorscanner-Vermeidung-Hindernissen-Navigation/dp/B07VLFGT27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
Capteur ultrason | 1 | 1.23 € | 1.23 € | 13 | https://fr.aliexpress.com/item/32880359778.html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
Servo SG90 | 2 | 1.90 € | 3.80 € | 9 | MG90S SG90 9g – avion télécommandé Miniature, équipement de direction à ailes fixes, modèle d'avion 250 450, hélicoptère, voiture jouet | AliExpress (https://fr.aliexpress.com/item/32807449919.html?pdp_npi=2%40d)
Caméra Raspberry Pi | 1 | 6.28 € | 6.28 € | 18.4 | https://fr.aliexpress.com/item/1005003187542470.html?scm_id=1007.40050.281175.0&scm-url=1007.40050.281175.0
Potentiometre 10K | 3 | 0.51 € | 3.53 € | 10 | https://fr.aliexpress.com/item/1005001421294754.html?scm_id=1007.40050.281175.0&scm-url=1007.40050.281175.0 | Color: 10 K Ohm
Accelerometre MPU6050 | 1 | 2.59 € | 2.59 € | 6 | https://fr.aliexpress.com/item/32340949017.html?curPageLogUid=c2sYDhCk9WsN
Prix total | 590.67 € | Poids total |  | 2333
 |  |  |  |  |  |  | 71
 |  |  |  |  |  |  | 60
 |  |  |  |  |  |  | 0
Nom | Quantité | Prix |  |  |  |  | 160
Corps et pattes |  |  |  |  |  |  | 1593.6
Tube en fibre de carbone | 1 tube | 23.36 € |  |  |  |  | 0
Plexiglass | 1 plaque | 23.37 €
Filament | 2kg | 40.00 €
Tige en acier 5mm | 1m | 10.00 €
Tige en acier 6mm | 1m | 10.00 €
Poulies | 12 | 1.11 € |  |  |  |  | 363
Courroie GT2 | 3m | 2.26 € |  |  |  |  | 13
Roulement 6mm (MR106ZZ) | 8 | 3.46 € |  |  |  |  | 18
Roulement 5mm (MR85ZZ) | 108 | 38.06 € |  |  |  |  | 18.4
Roulement 30mm (6906ZZ) | 12 | 11.40 € |  |  |  |  | 30
Visserie
M4 - 70mm | 48 | 14.16 €
M3 - 25mm | 24 | 5.40 €
M3 - 5mm | 68 | 3.70 €
M2 - 14mm | 24 | 4.60 €
M2 - 9mm | 16 | 7.00 €
M2 - 5mm | 8 | 4.80 €
Motorisation |  |  |  |  |  |  | 6
Brushless ACK-5312CP | 12 | 232.86 €
ESC 40A | 12 | 168.72 €
Électronique
Potentiometre 10K | 12 | 9.95 €
Arduino Mega 2560 Rev2 | 1 | 42.00 €
Sous-total composants : |  | 656.21 €
Heures de projets | 200 | 4750.00 €
Heures supplémentaires | 220 | 5225.00 €
Sous-total salaires : |  | 9975.00 €
Coût total du projet : |  | 10631.21 €

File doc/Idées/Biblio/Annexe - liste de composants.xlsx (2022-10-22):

Nom | Quantité | Prix | Prix total | Poids(g) | Lien | Description
Corps et pattes
Tube en fibre de carbone | 1 | 23.36 € | 23.36 € | 71 | https://fr.aliexpress.com/item/1005002248466483.html?curPageLogUid=nz516Ros1nuv | Color: 2pcs 30x28x500mm
Roulement | 8 | 0.95 € | 7.60 € | 5 | https://fr.aliexpress.com/item/32997948364.html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
Motorisation
Brushless ACK-5312CP | 12 | 26.10 € | 313.20 € | 155 | https://french.alibaba.com/product-detail/ACK-factory-High-End-Brushless-Motor-60113882656.html
ESC 40A | 4 | 27.65 € | 110.60 € | 132.8 | https://fr.aliexpress.com/item/4000292454786.html?_randl_currency=EUR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 | Color: 4xESC with wires
Capteurs
youyeetoo Slamtec RP LIDAR | 1 | 109.99 € | 109.99 € | 363 | https://www.amazon.fr/Scanradius-LIDAR-Sensorscanner-Vermeidung-Hindernissen-Navigation/dp/B07VLFGT27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
Capteur ultrason | 1 | 1.23 € | 1.23 € | 13 | https://fr.aliexpress.com/item/32880359778.html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
Servo SG90 | 1 | 1.90 € | 1.90 € | 9 | MG90S SG90 9g – avion télécommandé Miniature, équipement de direction à ailes fixes, modèle d'avion 250 450, hélicoptère, voiture jouet | AliExpress (https://fr.aliexpress.com/item/32807449919.html?pdp_npi=2%40d)
Caméra Raspberry Pi | 1 | 6.28 € | 6.28 € | 18.4 | https://fr.aliexpress.com/item/1005003187542470.html?scm_id=1007.40050.281175.0&scm-url=1007.40050.281175.0
Potentiometre 10K | 3 | 0.37 € | 2.10 € | 10 | https://fr.aliexpress.com/item/1005002766893077.html?scm_id=1007.40050.281175.0&scm-url=1007.40050.281175.0 | Color: 10 K Ohm
Accelerometre MPU6050 | 1 | 2.59 € | 2.59 € | 6 | https://fr.aliexpress.com/item/32340949017.html?curPageLogUid=c2sYDhCk9WsN
Prix total | 578.85 € | Poids total |  | 2941.6
 |  |  |  |  |  |  | 71
 |  |  |  |  |  |  | 40
 |  |  |  |  |  |  | 0
 |  |  |  |  |  |  | 1860
 |  |  |  |  |  |  | 531.2
 |  |  |  |  |  |  | 0
 |  |  |  |  |  |  | 363
 |  |  |  |  |  |  | 13
 |  |  |  |  |  |  | 9
 |  |  |  |  |  |  | 18.4
 |  |  |  |  |  |  | 30
 |  |  |  |  |  |  | 6

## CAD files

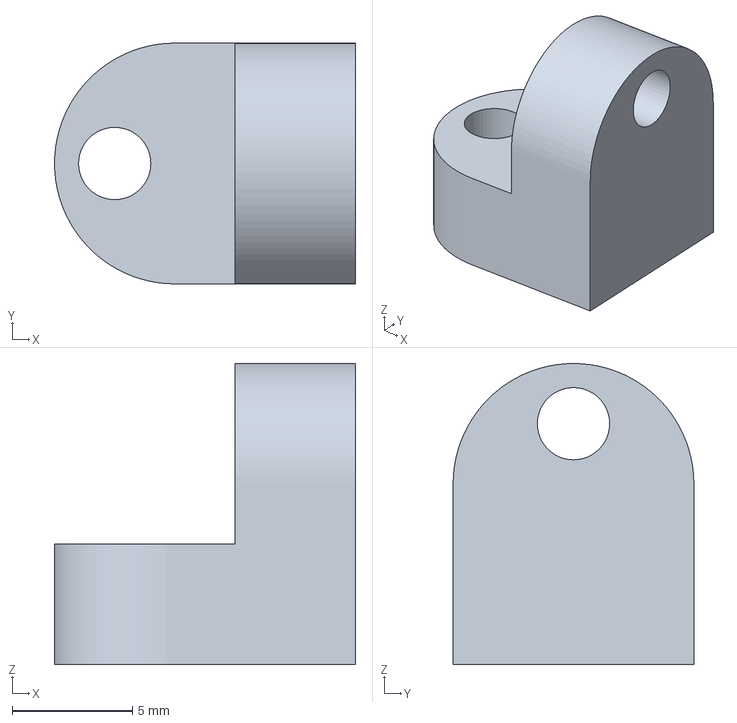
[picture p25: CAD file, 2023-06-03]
building/frame/bits/set_square_1.3mf
12.5 x 10.0 x 12.5 mm

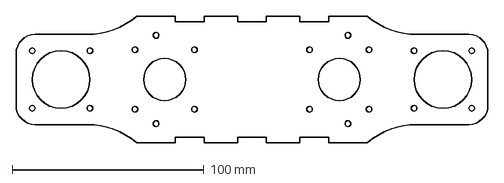
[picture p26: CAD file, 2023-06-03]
building/frame/head_support_frame.dxf
246.0 x 66.0 mm

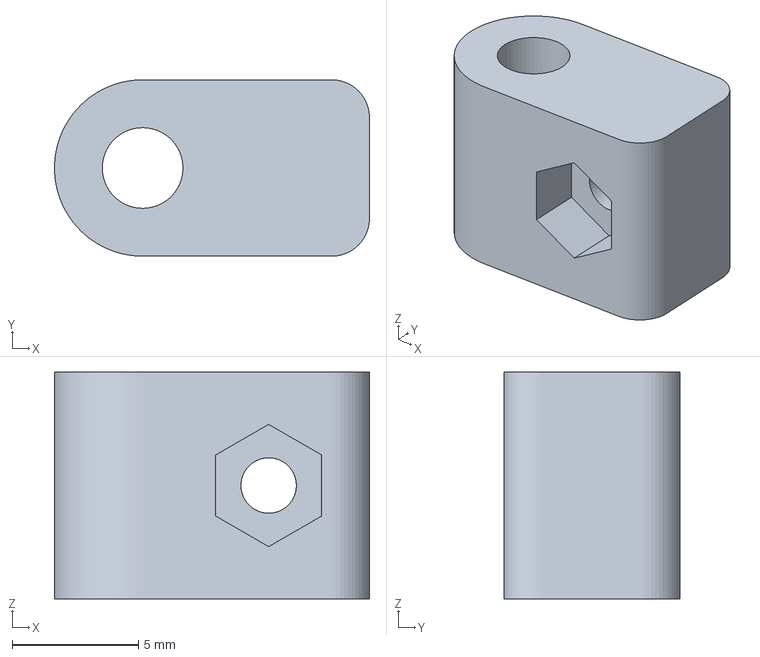
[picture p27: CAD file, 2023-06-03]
building/leg/belt_tensor/holder.3mf
12.5 x 7.00 x 9.00 mm

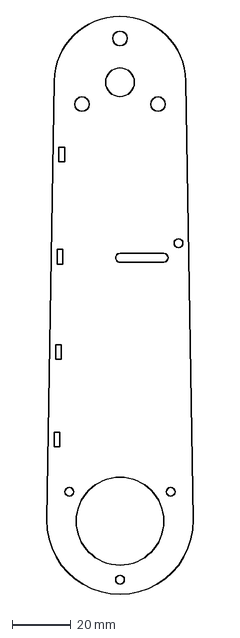
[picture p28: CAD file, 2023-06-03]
building/leg/bones/cuisse_3mm.dxf
50.3 x 198.6 mm

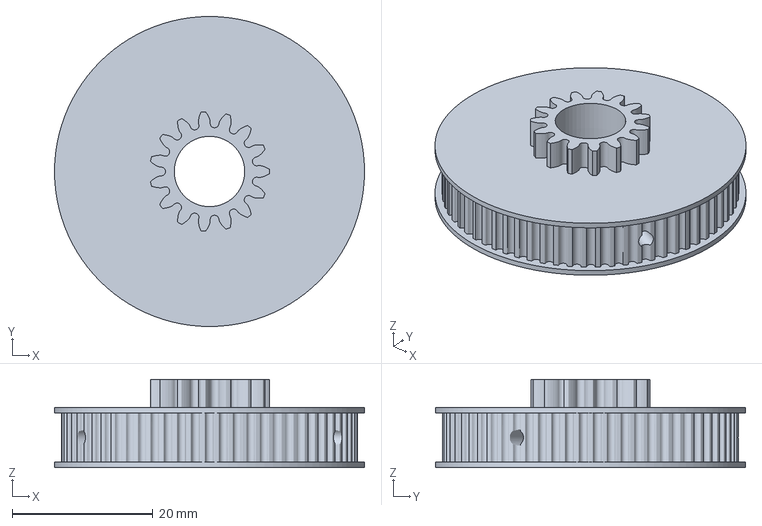
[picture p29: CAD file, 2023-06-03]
building/leg/hip/B1_simple+pot_v2.3mf
44.0 x 44.0 x 12.5 mm

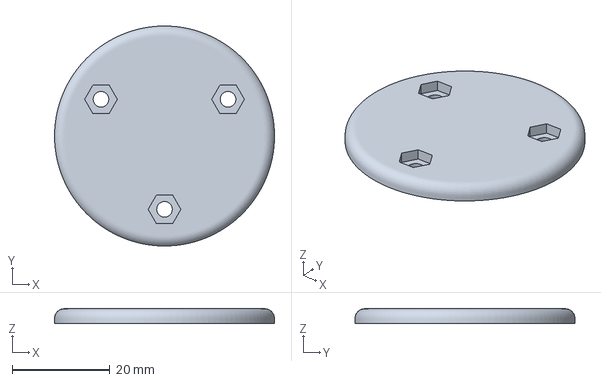
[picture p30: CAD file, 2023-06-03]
building/leg/knee/outside_knee_fixation.3mf
45.0 x 45.0 x 3.00 mm

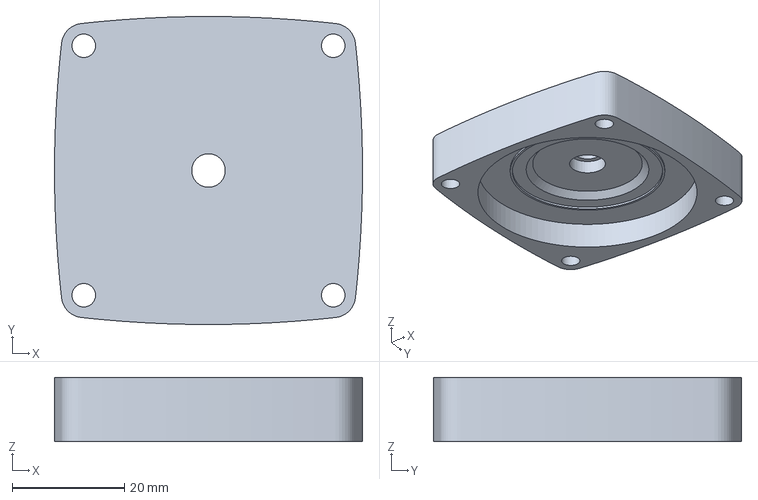
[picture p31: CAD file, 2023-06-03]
building/leg/motor-reducer/C3.3mf
55.0 x 55.0 x 11.5 mm

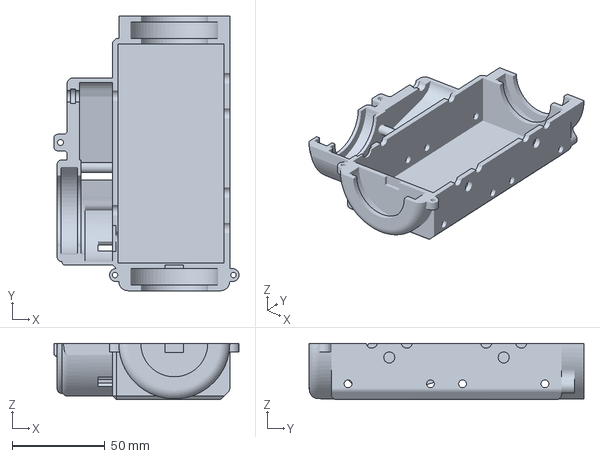
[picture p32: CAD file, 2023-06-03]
building/leg/shoulder/epaule_low.3mf
100.0 x 148.4 x 30.5 mm

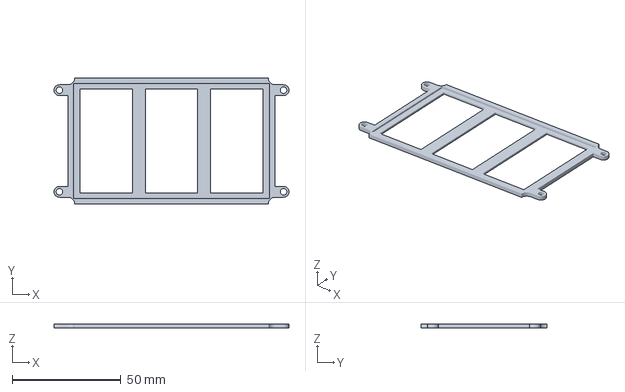
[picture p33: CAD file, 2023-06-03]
building/miscellaneous/esc_beds/esc_triple_bed.3mf
108.0 x 57.7 x 2.00 mm

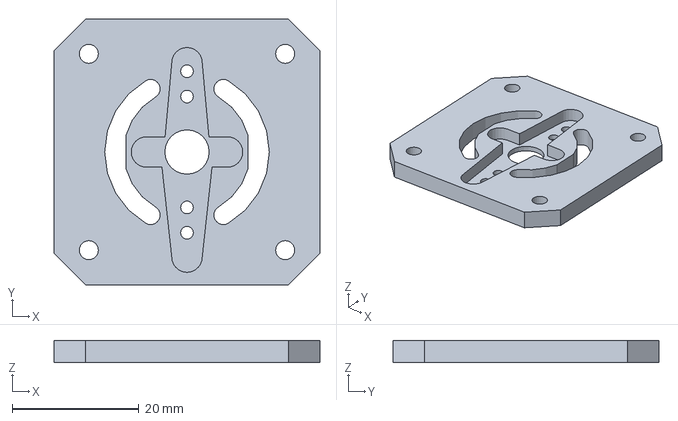
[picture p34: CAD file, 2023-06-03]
building/miscellaneous/head/base_mount.3mf
42.0 x 42.0 x 3.50 mm

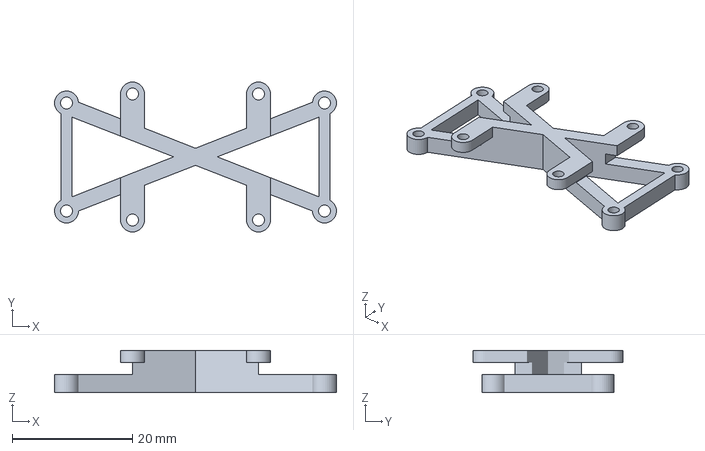
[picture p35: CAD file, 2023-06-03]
building/miscellaneous/head/fixations/fixation_hc_sr04.3mf
47.0 x 25.0 x 7.00 mm

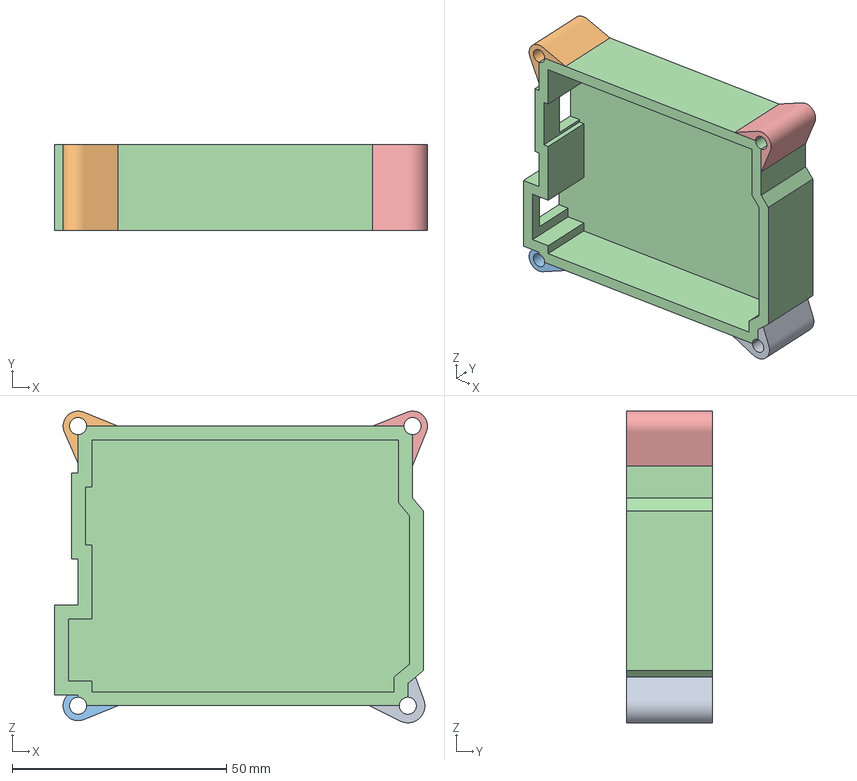
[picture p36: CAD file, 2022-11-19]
doc/Autres rendus/Boitier Arduino/Maximilien_Kulbicki/ArduiBox_Kulbicki.3mf
87.1 x 20.0 x 72.8 mm
Corps10
Corps11
Corps12
Corps2
Corps9

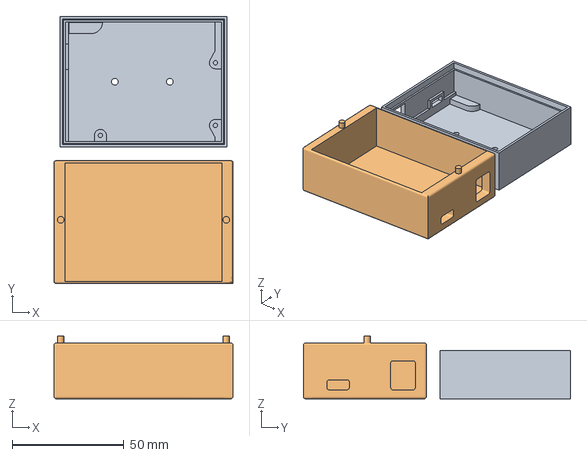
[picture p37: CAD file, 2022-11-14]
doc/Autres rendus/Boitier Arduino/Ronan_Le_Corronc/Boitier Arduino.3mf
80.0 x 119.4 x 28.0 mm
Boitier Arduino v3
Boitier_Arduino_Jimmy_2 v4.stl

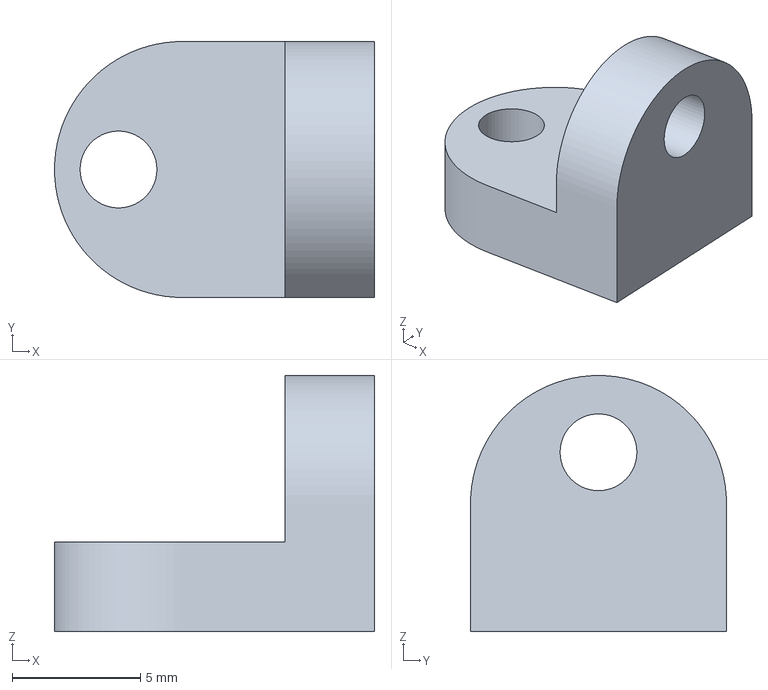
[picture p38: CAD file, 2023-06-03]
building/frame/bits/set_square_2.3mf
12.5 x 10.0 x 10.0 mm

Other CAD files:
building/frame/lining.dxf
building/leg/belt_tensor/rubber.3mf
building/leg/bones/tibia_6mm.dxf
building/leg/hip/hip_ring.3mf
building/frame/base.dxf
building/frame/bits/jetson-arduino_spacer.3mf
building/frame/bits/support_tube.3mf
building/frame/lateral_frame_jetson_holes.dxf
building/frame/motor_axis_guide_frame.dxf
building/leg/bones/Tibia.3mf
building/leg/hip/axe_guide_motor_hip.3mf
building/leg/hip/outside_hip_fixation.3mf
building/leg/hip/spurgear_paradise.3mf
building/leg/knee/inner_knee_fixation.3mf
building/leg/knee/outside_knee_fixation_potentiometer.3mf
building/leg/motor-reducer/C1.3mf
building/leg/motor-reducer/C2.3mf
building/leg/motor-reducer/P1.3mf
building/leg/motor-reducer/P12.3mf
building/leg/motor-reducer/Plexiglass_support_moteur_3mm.dxf
building/leg/motor-reducer/S1.3mf
building/leg/motor-reducer/S2.3mf
building/leg/shoulder/B1_ring.3mf
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

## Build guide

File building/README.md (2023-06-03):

# Notice

This section contains all the requiered elements for the building of the robot. 

You will find all the files under two extensions :

1. the ```.3mf``` extension for the 3D printed piece
2. the ```.dxf``` for the laser cut elements

The 3D printed piece can all be done using the same hard filament (PLA/ABS/PETG/...).

The laser cut elements must be cut in 3mm thick plexiglass (or wood). 

# Preview

The dog was designed under Fusion360. You can see the preview of the assembly in the image below. 

assembly

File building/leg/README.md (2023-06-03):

# Notice 

This section contains the elements allowing to build a leg.

Assemblage_jambe

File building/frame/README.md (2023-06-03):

# Notice 

This section covers the frame of the robot, the vessel for all the components. 

Most of the parts are cut in plexiglass (or wood) for a faster building time.

The other [bits](https://github.com/RonanLc/Snoopytech/tree/main/building/frame/bits) are used to maintain the frames together or for an external use. 

# Preview 

The assembly of the vessel can be seen in the following image : 

body

The order of the inner frames from left to right are : 
1. Head support
2. Linning
3. Plexiglass motor support (x2)
5. Motor axis guide (x2)
6. Plexiglass motor support (x2)
7. Linning 
8. Lateral jetson frame

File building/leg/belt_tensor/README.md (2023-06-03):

This section contains the tensor for the belt transmisson.

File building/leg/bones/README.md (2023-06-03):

# Notice 

This section contains the bones of the legs.

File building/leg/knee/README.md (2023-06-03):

# Notice 

This section contains the knee elements of the leg.

A potentiometer is mounted in the outside knee fixation (pot version).

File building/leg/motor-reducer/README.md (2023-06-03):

# Notice 

This section contains the motor-reducers of the leg.

[photo]

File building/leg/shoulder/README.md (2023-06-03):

# Notice 

This section contains the elements of the leg's shoulder.

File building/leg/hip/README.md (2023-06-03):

# Notice 

This section contains the hip elements.

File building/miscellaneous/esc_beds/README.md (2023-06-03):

This section contains all the requiered elements for the building of the robot.

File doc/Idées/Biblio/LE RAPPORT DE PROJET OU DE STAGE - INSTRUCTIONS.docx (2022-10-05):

Rapport de projet

Année scolaire 2022-2023

″Chien de surveillance″

Etudiants : Le Corronc Ronan et Kulbicki Maximilien

Ecole Polytechnique Universitaire de Nice Sophia-Antipolis, formation robotique (systèmes autonomes)

930 route des Colles, 06410 BIOT

SOMMAIRE

# Introduction

# Chapitre I : Structure

## I.1. Cahier des charges

## I.2. Corps

### I.2.1. Disposition des modules

### I.2.2. Options et solution

### I.2.3 Matériaux

## I.3. Pattes

### I.3.1 Options et solution

### I.3.2. Matériaux

# Chapitre II : Transmission mécanique et moteurs

## II.1 Puissance nécessaire

## II.2 Options et solution

# Chapitre III : Module de gestion de l'environnement

## III.1 Cartographie du milieu

### III.1.1 Besoin

### III.1.2 Options et solution

# Chapitre IV : Alimentation

## IV.1 Options et solutions

# Chapitre V : Répartition du travail

## V.1Tâches

## V.2 Diagramme de Gantt

## V.3 Equipement nécessaire

# Conclusion

Introduction

Dans le cadre de notre projet de 1ère année de Robotique, nous nous sommes lancé le défi de réaliser un robot imitant la physionomie d’un chien capable d’assurer la surveillance d’un bâtiment.

Notre objectif est de créer un robot pouvant soulager le personnel de sécurité travaillant la nuit, en effectuant des patrouilles plus ou moins longues au sein d’une zone à surveiller.

Notre robot se doit donc d’être autonome face aux différents signes d’intrusion (fracas, tremblements etc.) et doit pouvoir adapter ses déplacements en fonction de ceux-ci. Cela implique que notre robot-chien doit être capable de se repérer dans son environnement, se mouvoir dans des escaliers et avoir la possibilité d’ouvrir des portes.

Dans les délais qui nous sont accordés, nous n’estimons pas avoir le temps de réaliser un robot remplissant toutes ces fonctionnalités et avons donc sélectionné celles qui nous feraient progresser le plus et nous donneraient un bon aperçu des compétences à acquérir en robotique. Nous envisageons ainsi de produire un robot capable d’accomplir deux tâches : celle de se repérer dans un espace de travail donné et celle de se déplacer dans un escalier.

Pour rendre nos objectifs plus concrets, le bâtiment D des Templiers constituera la zone à surveiller puisqu’il présente les caractéristiques d’un bâtiment quelconque : plusieurs étages, escaliers et des couloirs. Nous supposerons que la zone à surveiller se limite aux couloirs des deux étages, sans l’ensemble des pièces séparées de ceux-ci par des portes.

Notre projet se décomposera selon deux axes de travail : un axe de travail cherchant à rendre le robot fonctionnel ; un axe de travail visant à le rendre autonome dans son espace.

# Chapitre I : La structure

Dans cette partie, nous définirons les caractéristiques physiques de notre robot.

## I.1. Cahier des charges

Les contraintes de taille que nous fixerons sont les suivantes :

- hauteur maximale : 240mm

- largeur : 80mm

- longueur maximale : 320mm

## I.2. Le corps

Cette partie concerne la pièce centrale du robot qui accueillera l’ensemble des modules et des pattes.

### I.2.1. Disposition des modules

(Schéma de la disposition des modules)

### I.2.2. Options et solutions

Pour le corps, nous avons besoin d’une surface pouvant contenir tous les modules du robot : cartes mères, capteurs, moteurs et transmissions.

Dans nos recherches, nous retrouvons principalement des corps cubiques et fermés. L’avantage de ceux-ci est qu’ils apportent une bonne robustesse mais ont l’inconvénient d’alourdir la structure.

Un autre type de structure apparait dans nos recherches. Il s’agit de corps maintenu par des tubes, sans parois latérales.

Nous opterons pour une carrosserie cubique, tout en veillant à la rendre poreuse lorsque c’est applicable afin de diminuer sa masse.

Notre châssis adoptera une forme en « I », comme illustré sur la figure I.

(Figure I)

### I.2.3. Matériaux

Parmi les matériaux disponibles pour la construction de notre châssis, nous cherchons ceux capables d’allier robustesse et légèreté.

Trois choix s’offrent à nous : plexiglass, acier/aluminium, bois.

(Tableaux avantages/inconvénients)

Nous avantagerons donc le plexiglass dans la création du châssis puisqu’il présente le compromis le plus avantageux. On se garde le droit d’utiliser l’aluminium pour les pièces qui nécessitent plus de solidité.

## I.3. Les pattes

Cette partie concerne les composants responsables des déplacements du robot.

### I.3.1. Options et solutions

Il existe deux types de format pour la structure des pattes de robot chien :

- les pattes reprenant l’anatomie d’une patte de chien.

- les pattes dites « en diamant ».

Les pattes de chien sont les plus courantes dans l’industrie des robot quadrupèdes. Elles sont notamment utilisées par des entreprises comme Boston Dynamics (voir figure I.3.1.1) ou Ghost Robotics. Ces pattes ont l’avantage d’être robustes lorsque l’appui est éloigné du corps.

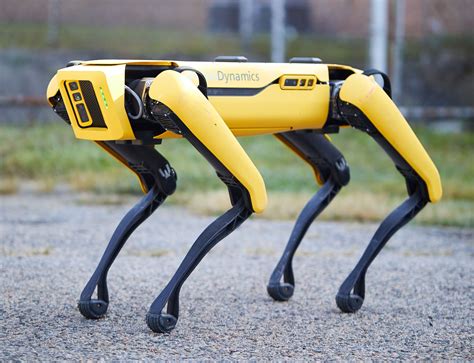
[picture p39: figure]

Figure I.3.1 : Robot quadrupède à pattes de chien de Boston Dynamics

Les pattes dites « en diamant » (voir figure I.3.2) ont été utilisées dans le projet StanfordDoggo, mené par les étudiants en robotique de Stanford. Elles ont l’avantage d’apporter un mouvement verticale fluide et controlé, qui permet au StanfordDoggo de sauter et faire des pirouettes.

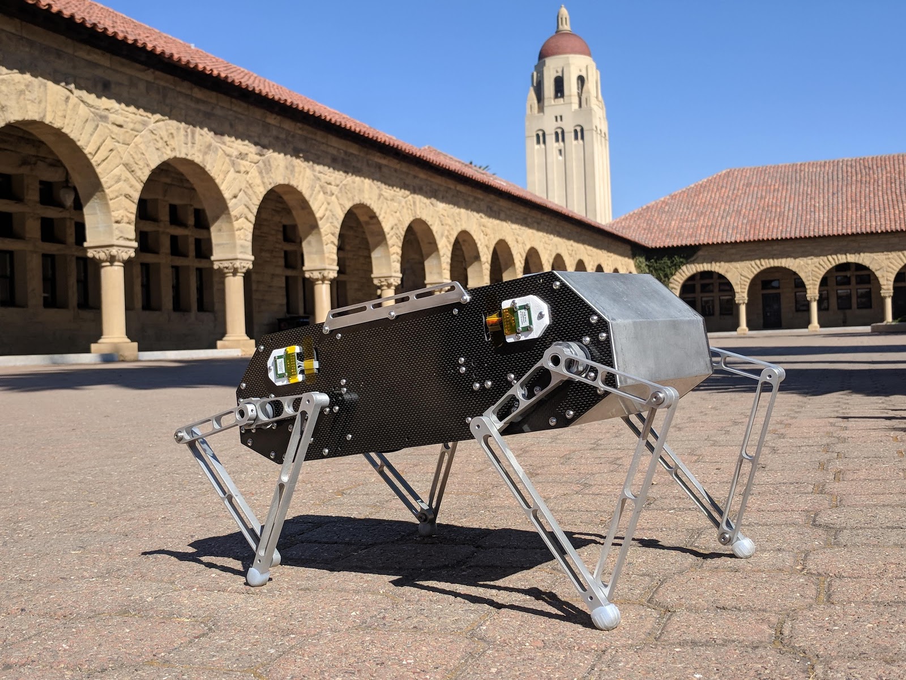
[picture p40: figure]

Figure I.3.2 : Le robot StanfordDoggo aux pattes « en diamant ».

### I.3.2. Matériaux

# Conclusion

Vous devez résumer (rappeler) les avancées de votre travail en accord avec les objectifs définis dans le cahier des charges. Vous devez dire ce qui fonctionne et ce qui ne fonctionne pas et pourquoi. Il faut donner des perspectives concrètes à votre travail en imaginant que quelqu’un va le poursuivre.

Il faut bannir toutes les phrases du type : j’ai beaucoup aimé ce projet / cela m’a appris le travail en équipe…. En clair il ne faut pas étaler vos états d’âme : votre conclusion doit rester technique

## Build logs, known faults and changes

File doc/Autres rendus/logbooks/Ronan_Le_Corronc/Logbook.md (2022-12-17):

# Week 2 - Feminism

## Quote of the day

**As long as she thinks of a man, nobody objects to a woman thinking.**  - *Virginia Woolf, author*

Virginia Woolf refers to the fact that in the heart of today's society, a woman will not be able to do otherwise than think or link her life to man. She refers to the fact that man is the main element of society and nothing can happen without it.

<br>

## "Gender consideration" part 2 (After Perk of the job):  What is feminism or what should it be according to you?

For me, I believe that feminism does not exist.

I am aware of it and I totally understand the movement but I find the name given unjustified. Feminism advocates **the equality of men and women**, nothing more, nothing less. To designate someone as a feminist is to designate someone who is looking for equality between men and women, so I think the term is misused. For example, today a person wanting equality between a black person and a white person is someone considered normal, the opposite would be a racist. I consider gender equality in a similar way. A person seeking gender equality should not be a feminist, but rather a normal person. And so femisimne should be a normality and not a movement.

The Bechdel test is a test aimed at films or video to know if yes or no, women will be concerned in the film. To do this it seeks to verify 3 rules :

- Two female characters
- Who talk to each other
- about something else than a man

I don't think you can use this test to have a more feminist or non-feminist approach in a film. I consider that it is very good as a stastistic but not further. To check if a film passes the test or not would logically push to modify some elements of the film in order to validate this test, and here, the result would be anything but feminist. In comparison, it would be to say "This character will be black because we need a black person in the movie so that it doesn't look racist", no, it's the opposite. Every choice of character should be justified or not according to the story and the character that has to be played, not only because of the gender of the person.

So I don't consider the interest of setting up a test, whether it's this one or a new one for the creation of a new movie, but I still think that they are very interesting for statistics.

<br>

# Week 1 - Weird but fun

## Quote of the day

**Inside every cynical person, there is a disappointed idealist.** - *George Carlin , Comedian*

Every person who has chosen to break out of the societal codes has been deeply disappointed by something, whether it is due to society, an element that they cannot control and that they cannot change at their own level (like climate, economic functioning, etc.) or due to personal events, to encounters that have taken place in their lives.

<br>

## Musical Interlude

**The lazy song** - *Bruno Mars*

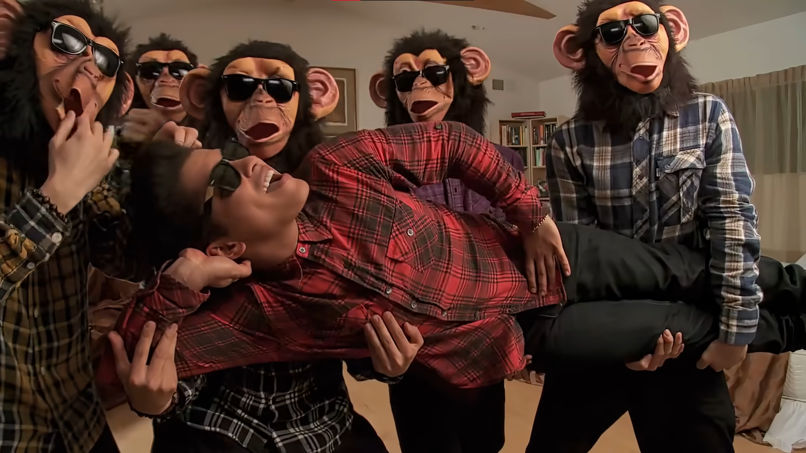
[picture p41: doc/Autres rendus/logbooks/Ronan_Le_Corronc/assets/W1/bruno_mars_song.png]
The lazy song


Music result

I did this exercise in intermediate. Sometimes I had a little difficulties so I didn't try a more complicated level.

<br>

## Storytelling Part 1 : Uncharted territory for some- Stand-up comedy in English

I chose for this exercise the sketch **Robin Williams - Alcoholism**. Here as its name indicates it, he tries to highlight the behavior and the problems of alcohol. To do this, he tells a story by including himself in it, he will describe himself as an alcoholic and therefore tell banalities as if it were his experience. He will follow a guideline while quickly rambling on many different anectodes and playing the characters of these anectodes. His humor works very well on me because his jokes are always completely unexpected and well acted.

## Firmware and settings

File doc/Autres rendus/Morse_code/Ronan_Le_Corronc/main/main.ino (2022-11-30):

/*

  ########  Développé par Ronan Le Corronc  #######
  ###  Étudiant en ROB3 à Polytech Nice-Sophia  ###
  ################  Novembre 2022  ################


Ce programme permet d'afficher, à l'aide d'une LED sur une carte arduino, une phrase traduite en morse.

Il est composé de 7 sous fichiers, sans lesquels le code risque de ne pas fonctionner :
  - main.ino
  - LettreMorse.h
  - LettreMorse.cpp
  - Translation.h
  - Translation.cpp
  - SentenceSplit.h
  - SentenceSplit.cpp

Le programme fonctionne de la façon suivante :

  - Il enregistre la phrase à traduire (ligne 46)

  - Il récupère une seule lettre de la phrase

  - Il traduit la lettre en morse

  - Il traduit le morse en une trame temporelle binaire correspondant à l'état de la LED au fil du temps
    (par exemple,   en morse, le A = .-   / la trame temporelle sera donc : 0101110)
    (autre exemple, en morse, le F = ..-. / la trame temporelle sera donc : 01010111010)

  - Il active la LED en fonction de la trame temporelle sans "bloquer" le programme grace à la fonction millis()

  - Il retourne chercher récupérer la lettre suivante de la phrase (ligne 22)
*/


#include "Arduino.h"
#include "LettreMorse.h"
#include "Translation.h"
#include "SentenceSplit.h"

LettreMorse lm;
Translation tr;
SentenceSplit ss;

const char* phrase = "Veuillez entrer une phrase à traduire...";    // Phrase à afficher en morse     <--------- ############### VALEUR A MODIFIER ###############

const int blinkSpeed = 200;         // Correspond à la durée des périodes de la LED (passage entre éteint et allumé)
int tramCursor;                     // tramCursor permet de venir lire, caractère par caractère, la trame temporelle correspondant à l'affiche en morse sur la LED. IL fonctionne comme un curseur dans une trame de valeur


void setup() {

  Serial.begin(9600);               // Initialise la communication en série entre l'ordinateur et la carte Arduino
  Serial.println("Starting...");

  pinMode(LED_BUILTIN, OUTPUT);     // Initialise la LED
  ss.initialisation(phrase);        // Initialise la phrase à traduire

}


void loop() {

  if (ss.available() > 0 && tramCursor >= tr.binary_tram_size) {    // Boucle permettant de traduire une lettre en morse, elle sera utilisé pour chaque lettre de la phrase  /  (Tant qu'il reste des lettres à lire  &&  Une fois que la trame précédente à entièrement été lu )

    tramCursor = 0;                   // Remet le curseur au début de la trame

    lm.morseConverter(ss.read());     // Convertit la lettre reçu en morse

    tr.binaryMorse(lm.morse);         // Convertit le morse en trame temporelle binaire (correspondant à l'état de la LED au fil du temps)

    Serial.print(phrase[ss.cursor]);  // Indique sur le moniteur la lettre affichée en morse
    Serial.print(" : ");
    Serial.println(lm.morse);         // Indique sur le moniteur la traduction en morse de la lettre

  }

  if (millis()%blinkSpeed < 1 && tramCursor < tr.binary_tram_size){   // Boucle permettant d'afficher le morse sur la LED sans "bloquer" le programme et la carte arduino  /  (  &&  Tant que toute la trame n'a pas été lu )

    digitalWrite(LED_BUILTIN, tr.binary_tram[tramCursor]);    // Allume ou éteint la LED
    tramCursor++;                                             // Déplace le curseur au caractère suivant

  }
  
  delay(1);   // limite la vitesse de répétition de la boucle loop()
}

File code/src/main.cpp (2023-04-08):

//#include "Gyroscope.hpp"
//#include "CameraMount.hpp"
#include "MotorJoint.hpp"

/*

// // Gyro
Gyroscope gyro;
float ypr[3]; // container for yaw pitch roll

// // Camera mount 1

const uint8_t foot=5;
const uint8_t body=3;
CameraMount support1(body,foot);
int container[2];

// // Camera mount 2

const uint8_t foot2=9;
const uint8_t body2=10;
CameraMount support2(body2,foot2);
int container2[2];

*/

// Genou front right 
const uint8_t pot_genou_fr=A1; // pot dans le genou
int esc_genou_fr=5;
const uint8_t control_genou_fr=A0; // donne l'angle à atteindre
MotorJoint genou_fr(esc_genou_fr,pot_genou_fr, 26,178,170,-1);

// Hanche front right
const uint8_t pot_hanche_fr=A2;
int esc_hanche_fr=6;
const uint8_t control_hanche_fr=A3;
MotorJoint hanche_fr(esc_hanche_fr,pot_hanche_fr,60,160,145,-1);

// Epaule front right
const uint8_t pot_epaule_fr=A4;
int esc_epaule_fr=9;
const uint8_t control_epaule_fr=A5;
MotorJoint epaule_fr(esc_epaule_fr,pot_epaule_fr,11,164,100,1);


void setup() {
  Serial.begin(9600);

  //gyro.setup_gyro();

  //support1.setup_cm();
  //support2.setup_cm();

  genou_fr.setup_mj();
  hanche_fr.setup_mj();
  epaule_fr.setup_mj();
}

void loop() {

  //gyro.get_yaw_pitch_roll(ypr);
  // Serial.print(ypr[0]);
  // Serial.print("  ");
  // Serial.print(ypr[1]);
  // Serial.print("  ");
  // Serial.print(ypr[2]);
  // Serial.println("  ");


  //support1.move(-ypr[2],ypr[1]);
  //support2.move(-ypr[2],ypr[1]);
  // Serial.print(analogRefr(A0));
  // Serial.print("   ");
  
  // Serial.print("   ");
  // Serial.print(foot.refr());

  // Serial.print("  ");
  // Serial.println(map(-45,-90,90,750,2250));

  // support1.move_x(map(analogRefr(pot),0,1023,-90,90));
  // support1.get_position(container);
  // Serial.print(analogRefr(pot));
  // Serial.print(map(analogRefr(pot),0,1023,-90,90));
  // Serial.print("  ");
  // Serial.print(container[0]);
  // Serial.print("  ");
  // Serial.println(container[1]);

  // // test genou front right
  // uint16_t setAngle = map(analogRead(control_genou_fr),0,1023,0,90);
  // genou_fr.set_angle(setAngle);
  // Serial.print(map(analogRead(control_genou_fr),0,1023,0,90));
  // Serial.print("  ");
  // Serial.print(genou_fr.get_angle());
  // Serial.print("  ");
  // Serial.println(genou_fr.get_speed());

  //   // test hanche front right
  // uint16_t setAngle = map(analogRead(control_hanche_fr),0,1023,0,90);
  // hanche_fr.set_angle(setAngle);
  // Serial.print(map(analogRead(control_hanche_fr),0,1023,0,90));
  // Serial.print("  ");
  // Serial.print(hanche_fr.get_angle());
  // Serial.print("  ");
  // Serial.println(hanche_fr.get_speed());

    // test epaule front right
  uint16_t setAngle = map(analogRead(control_epaule_fr),0,1023,0,90);
  epaule_fr.set_angle(setAngle);
  Serial.print(map(analogRead(control_epaule_fr),0,1023,0,90));
  Serial.print("  ");
  Serial.print(epaule_fr.get_angle());
  Serial.print("  ");
  Serial.println(epaule_fr.get_speed());

}

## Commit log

2022-09-16 Compte rendu hebdomadaire
    Création des comptes rendus
2022-10-05 Upload liste de composant
    [Annexe - liste de composants.xlsx]
2022-10-05 Recherches sur les capteurs et le fonctionnement du robot
2022-10-06 journée work BU
    [Annexe - liste de composants.xlsx]
2022-10-07 Création dossier doc
    [Annexe - liste de composants.xlsx]
2022-10-07 Update liste composant
    [Annexe - liste de composants.xlsx]
2022-10-07 Ajout barre carbone
    [Annexe - liste de composants.xlsx]
2022-10-07 Ajout capteur ultrason + servo
    [Annexe - liste de composants.xlsx]
2022-10-07 Update liste compo
    [Annexe - liste de composants.xlsx]
2022-10-07 Ajout Gantt
    [gantt.xlsx]
2022-10-07 Update Gantt
    [gantt.xlsx]
2022-10-08 Maj du Gantt
    [gantt.xlsx]
2022-10-08 Update liste de composant
    [Annexe - liste de composants.xlsx]
2022-10-14 Changement potentiometre
    [Annexe - liste de composants.xlsx]
2022-10-15 Ajout rapport
    Ajout rapport MK + pièces corps
    [Assemblage_corps v6.3mf, chassis_lateral_cadre v3.3mf, entretoise v3.3mf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]
2022-10-15 Rapport de la semaine 41
    [Annexe - liste de composants.xlsx]
2022-10-15 Déplacement liste de composants
    [Liste de composants.xlsx]
2022-10-18 Update liste_compo
    [Liste de composants.xlsx]
2022-10-22 2nd report - week 42
    [Annexe - liste de composants.xlsx]
2022-10-22 Update liste de compo
    [Liste de composants.xlsx]
2022-11-14 Upload rendu boitier Arduino
    [Boitier Arduino.3mf, Boitier Arduino.f3d]
2022-11-14 Arduino Box _ MK
    [ArduiBox_Kulbicki.3mf, ArduiBox_Kulbicki.f3d]
2022-11-15 add lib & add mpu6050/i2cdev
2022-11-19 Report 4 - RLC
    [Liste de composants.xlsx]
2022-11-30 gestion des chiffres
2022-12-05 Upload transmission research
    [pulley.ods]
2022-12-10 Libraries for stable camera mount
2022-12-10 Upload 3D files
    [C1 v4.stl, C1.3mf, C2 v6.stl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]
2022-12-10 Gy-521 and CameraMount Libraries
2022-12-10 Cleaning up
    [Assemblage_corps v6.3mf, chassis_lateral_cadre v3.3mf, entretoise v3.3mf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]
2022-12-10 Update ServoTimer2
2022-12-11 Upload Session 6 & 7 report
    [pulley.ods]
2022-12-17 Upload session 8 report
    [C1 v4.stl, C1 v5.stl, C2 v6.stl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]
2023-01-06 Upload pulley.ods
    [pulley.ods]
2023-01-21 Upload session 10 report - RLC
    [pulley.ods]
2023-02-12 Importation fichier 3D
    [C1 v5.3mf, C1 v5.stl, C1.3mf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]
2023-03-28 Upload building part
    [Reducteur_complet.3mf, cle_du_paradis v7.3mf, spurgear_paradis v5.3mf]
2023-04-04 change motorjoint
2023-04-05 upload motor control code
2023-05-16 Upload project report
    [Liste de composants.xlsx]
2023-06-03 update_building
    moved set squares to bits
    [set_square_1.3mf, set_square_2.3mf]
